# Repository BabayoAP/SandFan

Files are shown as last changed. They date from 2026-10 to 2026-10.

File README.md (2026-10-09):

# SandFan

My project for Half-Life by Hack Club!

Meant for climbers, a two-in-one portable device:
 - Variable speed enclosed fan for drying out wet hands on one side.
 - Variable speed skin-sander for grinding down overgrown calluses.

## How it works
A Seeed XIAO RP2040 is the controller. It sits on a 1S LiPo battery through a slide switch.

- **Power:** The battery feeds the motors directly (about 3.0 to 4.2 V). An AP2112K low-dropout regulator makes 3.3 V for the logic. The XIAO's own USB-C port charges the battery through an MCP73831 charger (about 200 mA), so there is no second USB connector. The battery can be charged while the switch is off.
- **Motor drive:** Each motor has its own AO3400A logic-level N-MOSFET on the low side, driven by a 20 kHz PWM pin from the RP2040. A 100 ohm gate resistor and a 100k pulldown keep the motors off while the MCU boots. An SS14 flyback diode and a 100 nF cap sit across each motor.
- **Stall protection:** The sander's MOSFET source goes to ground through a 0.1 ohm shunt. The voltage across it is filtered (1k and 100 nF) and read by an ADC pin. If the current stays above the limit for 150 ms, the firmware stops the sander and holds it off for 2 s, blinking its LED.
- **Buttons:** Five tactile buttons: fan up, fan down, sander up, sander down, and stop (everything off). Speed has 5 steps per motor. Three LEDs show fan, sander and charge state.
- **Low battery:** A 1:2 divider lets the MCU read the battery voltage. Motors are cut off below 3.3 V.

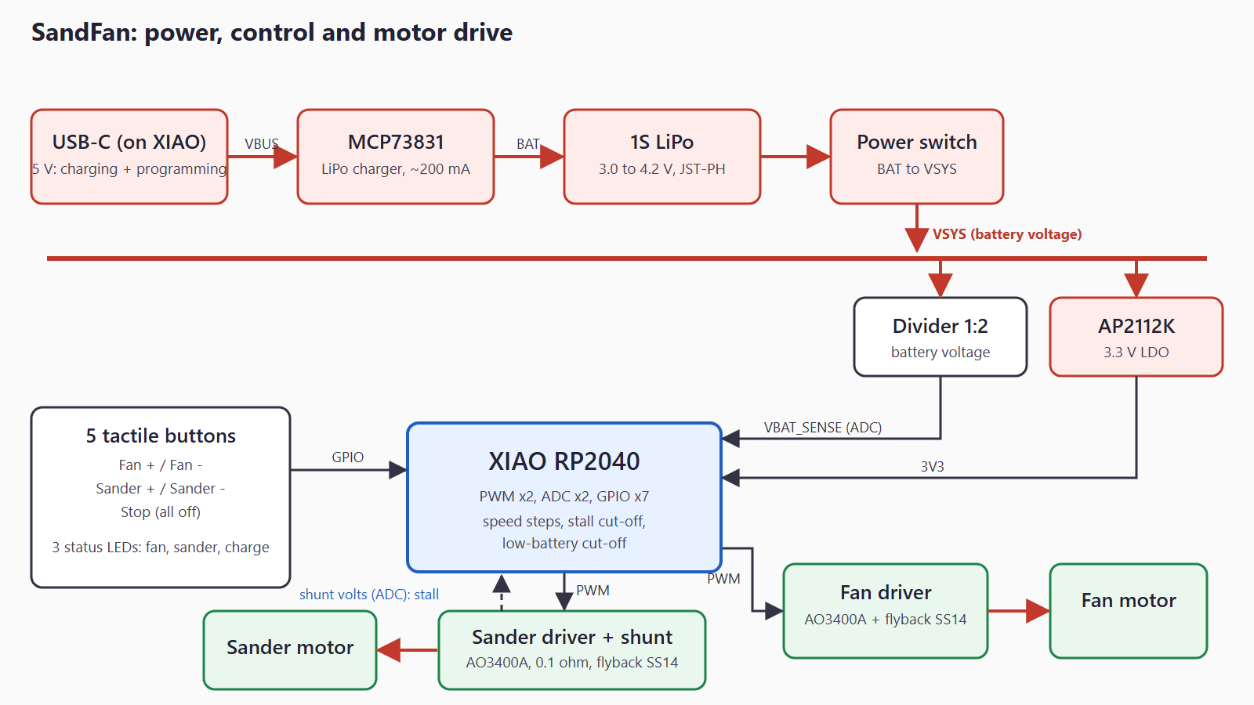
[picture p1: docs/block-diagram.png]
Block diagram


## Schematic and board
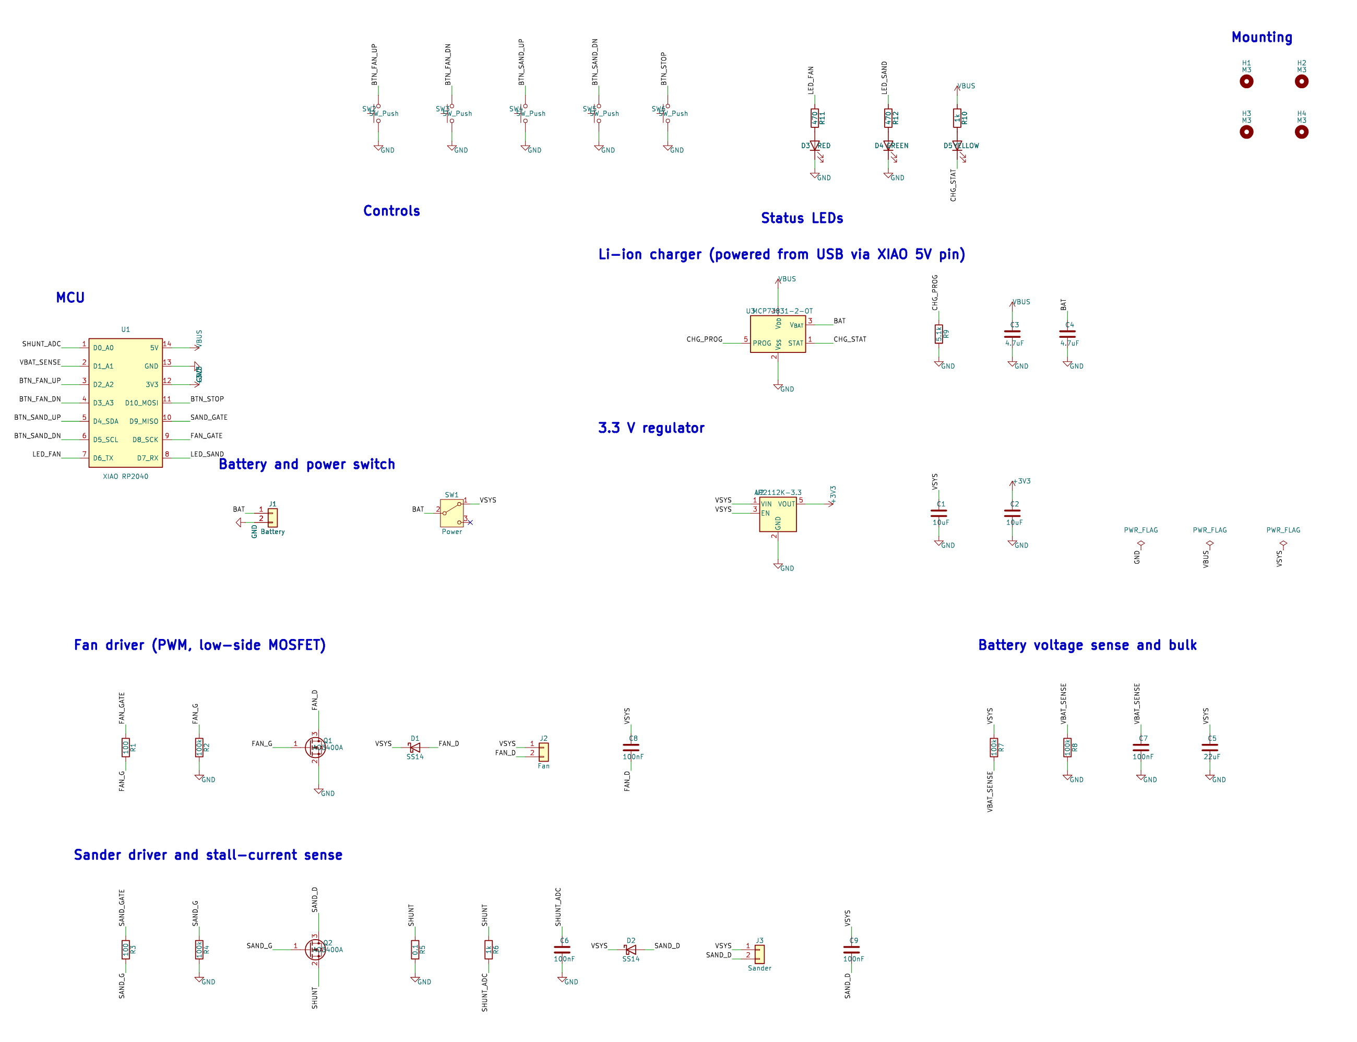
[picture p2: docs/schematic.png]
Schematic

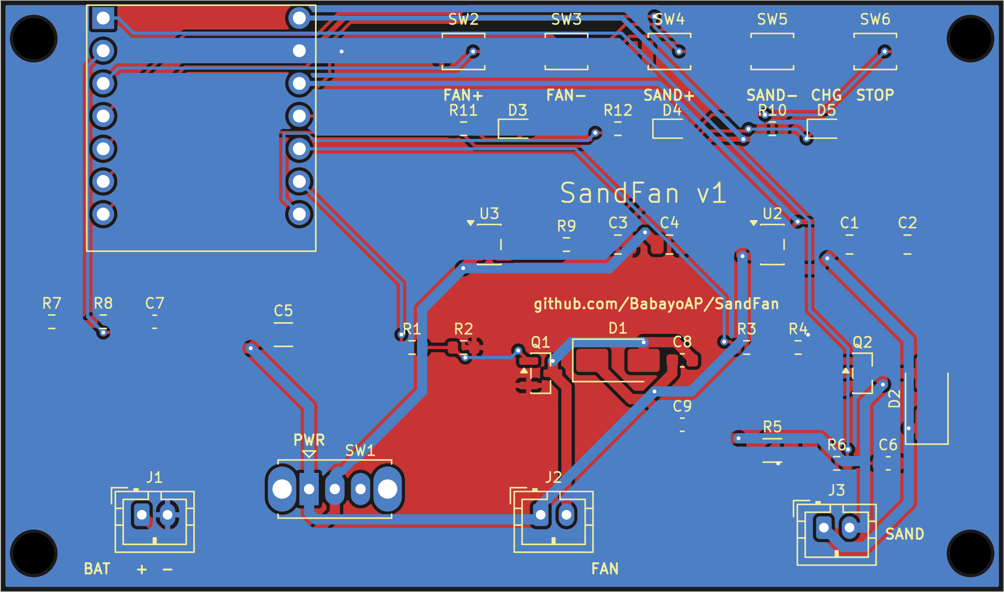
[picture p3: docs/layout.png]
Board layout

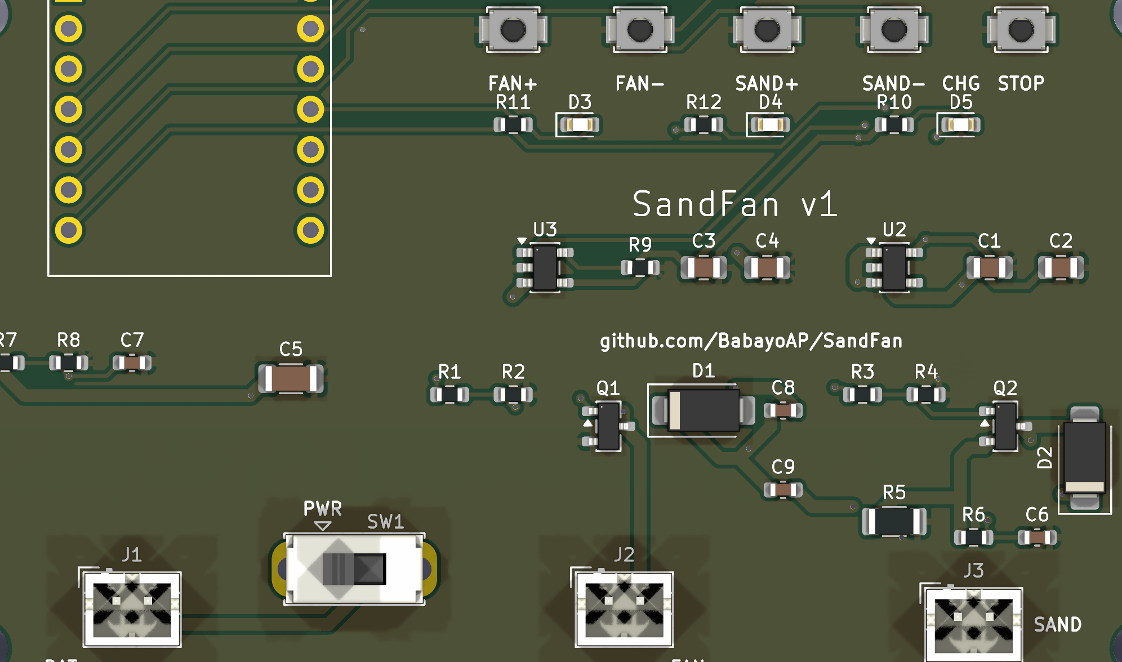
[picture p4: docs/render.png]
3D render


The board is 78 x 46 mm, two layers, with a ground pour on both sides. The XIAO's USB-C port sits at the board edge. ERC and DRC both pass with 0 violations in KiCad 10.

## Wiring
Everything on the board is soldered. The only hand-wired parts are the three things that plug in with JST-PH 2-pin connectors:

| Connector | Pin 1 | Pin 2 |
|---|---|---|
| J1 Battery | + | - |
| J2 Fan motor | VSYS (battery +) | motor return (switched by MOSFET) |
| J3 Sander motor | VSYS (battery +) | motor return (switched by MOSFET) |

LiPo packs are not standardized. Check your pack's polarity before plugging it in. Use a protected cell. Motor polarity only sets the spin direction.

## Bill of materials
| Part | Qty | Price | Link |
|---|-----|---|---|
| Seeed XIAO RP2040 (plus 2x 1x7 2.54 mm headers) | 1 | TBD | TBD |
| MCP73831T-2ACI/OT charger | 1 | TBD | TBD |
| AP2112K-3.3 regulator | 1 | TBD | TBD |
| AO3400A N-MOSFET | 2 | TBD | TBD |
| SS14 Schottky diode (SMA) | 2 | TBD | TBD |
| 0.1 ohm 1% 0.5 W resistor (1206) | 1 | TBD | TBD |
| B3U-1000P tactile switch | 5 | TBD | TBD |
| OS102011MS2QN1 slide switch | 1 | TBD | TBD |
| JST-PH B2B-PH-K-S connector | 3 | TBD | TBD |
| LEDs 0603 (red, green, yellow) | 3 | TBD | TBD |
| Resistors 0603 (100, 470, 1k, 5.1k, 100k) | 12 | TBD | TBD |
| Capacitors (100 nF, 4.7 uF, 10 uF, 22 uF) | 9 | TBD | TBD |
| 1S LiPo battery, protected | 1 | TBD | TBD |
| Fan motor and sander motor | 2 | TBD | TBD |

Prices and links get filled in when parts are ordered. The full line-by-line list with designators is in [bom.csv](bom.csv).

## Repo layout
- hardware/ : KiCad files, Gerbers zip
- firmware/ : source code
- docs/ : images
- bom.csv

## Status and next steps
**Done:** schematic, PCB (fully routed), Gerbers and drill files (`hardware/sandfan_gerbers.zip`), BOM, firmware first draft.

**Checked:** ERC and DRC pass in KiCad 10.0.6. The schematic netlist was cross-checked against the intended connections, and the board has 0 unconnected items.

**Not yet tested:**
- The firmware has not been compiled or run. It targets the arduino-pico core on a XIAO RP2040 and its pin map matches the schematic.
- No board has been built. The XIAO footprint (2x7, 2.54 mm pitch, 15.24 mm between rows) is from memory of the module, so measure the real module against it before ordering.
- The motors are not chosen yet. The stall current limit (1.5 A) and the 0.1 ohm shunt need to be sized to the real sander motor, and the shunt should be rated for the stall current.
- When USB is plugged in, the XIAO's own 3.3 V regulator and the AP2112K both drive the 3V3 rail. This is expected to be fine, but it is not verified on hardware.

**Build week:** order the board and parts, build it, compile and flash the firmware, tune the stall threshold with the real motor, then pick an enclosure and fit the fan and sander.

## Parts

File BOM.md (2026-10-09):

# SandFan – bill of materials

<!-- Generated by Half Life from project cmuuucq2k0am301smbv5bwrh2. Edits here are overwritten on the next sync. -->
<!-- Generated: 2026-10-09T06:47:38.833Z -->

> [!NOTE]
> This parts list is mirrored from [Half Life](https://halflife.hackclub.com). Editing it here will not change the platform's copy, and the next sync overwrites this file.

| Week | Tier | Parts funding |
| --- | --- | --- |
| Week 1 | Tier 3 | $100.00 |

| Part | What it's for | Qty | Unit | Total | Vendor |
| --- | --- | --- | --- | --- | --- |
| [WINSINN 50mm 5015 Blower Fan 5V, 4-pack](https://www.amazon.com/WINSINN-6000PRM-Hydraulic-50mmx15mm-Brushless/dp/B0DJQTXQ6D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) | Key c6000PRM, 3D Printer 5 Volt Fans Blower Turbine Turbo Homponent: move air over climber's hand to dry and remove sweat | 1 | $10.99 | $10.99 | [Amazon](https://www.amazon.com/WINSINN-6000PRM-Hydraulic-50mmx15mm-Brushless/dp/B0DJQTXQ6D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) |
| [2Pcs DC 6V 1000RPM Gear Motor](https://www.amazon.com/1000RPM-Geared-Gearwheel-Reduction-Robort/dp/B0DK77J793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) | Drives the callus sanding drum | 1 | $8.99 | $8.99 | [Amazon](https://www.amazon.com/1000RPM-Geared-Gearwheel-Reduction-Robort/dp/B0DK77J793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) |
| [Gebildet 2pcs PWM Low Voltage Motor Speed Controller DC](https://www.amazon.com/Gebildet-Adjustable-Driver-Controller-Voltage/dp/B08JPS6DDP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) | Dynamically controls the speed of the blower fan and the sander motor independently. | 1 | $5.69 | $5.69 | [Amazon](https://www.amazon.com/Gebildet-Adjustable-Driver-Controller-Voltage/dp/B08JPS6DDP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) |
| [Samsung 30Q 18650 3000mAh 15A Battery](https://www.18650batterystore.com/products/samsung-30q?_pos=1&_sid=ea73f6b51&_ss=r) | Energy Storage | 1 | $6.99 | $6.99 | [18650batterystore](https://www.18650batterystore.com/products/samsung-30q?_pos=1&_sid=ea73f6b51&_ss=r) |
| [Aokin 4pcs 18650 Battery Holder Bundle with Wire](https://www.amazon.com/Aokin-Battery-Storage-Parallel-Batteries/dp/B07Q13T3RH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) | Holding batteries, and providing contacts/leads | 1 | $4.99 | $4.99 | [Amazon](https://www.amazon.com/Aokin-Battery-Storage-Parallel-Batteries/dp/B07Q13T3RH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) |
| [ISDVBUY Mini Rocker Switch, 5-pack](https://www.amazon.com/ISDVBUY-Rocker-Electrical-Projects-Electricians/dp/B0DX6F2N4V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) | On/off switch | 1 | $3.99 | $3.99 | [Amazon](https://www.amazon.com/ISDVBUY-Rocker-Electrical-Projects-Electricians/dp/B0DX6F2N4V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) |
| [AOICRIE 6pcs Type-C USB 5V 2A Boost Converter](https://www.amazon.com/AOICRIE-Converter-Discharge-Integrated-Protection/dp/B0DLGTM47G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) | Charges battery via USB-C and protects it, boosts 3.7V to 5V for motors | 1 | $8.99 | $8.99 | [Amazon](https://www.amazon.com/AOICRIE-Converter-Discharge-Integrated-Protection/dp/B0DLGTM47G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) |
| [22awg Silicone Electrical Wire Cable 2 Colors](https://www.amazon.com/Electrical-Gauge-Silicone-Cable-Black/dp/B0746HG158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) | Connects battery, switch, controllers, and motors | 1 | $5.18 | $5.18 | [Amazon](https://www.amazon.com/Electrical-Gauge-Silicone-Cable-Black/dp/B0746HG158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) |
| [M2 M3 M4 Self Tapping Screws for Plastic, Carbon Steel](https://www.amazon.com/Tapping-Screws-Plastic-Carbon-Steel/dp/B0H8CD8MYV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) | Fasten the components and enclosure together | 1 | $8.99 | $8.99 | [Amazon](https://www.amazon.com/Tapping-Screws-Plastic-Carbon-Steel/dp/B0H8CD8MYV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) |
| [210 Pcs Heat Shrink Tubing Kit](https://www.amazon.com/Eugiichr-210PCS-Heat-Shrink-Tubing/dp/B0GGGY2HFJ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) | Wiring insulation | 1 | $6.19 | $6.19 | [Amazon](https://www.amazon.com/Eugiichr-210PCS-Heat-Shrink-Tubing/dp/B0GGGY2HFJ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) |
| [Gebildet 3V-6V-12V-24V-230V/1A 10pcs](https://www.amazon.com/Gebildet-3V-6V-12V-24V-230V-Prewired-Momentary-Railway/dp/B0CJHXJWN3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) | Primary switch for power, backup for rocker switch | 1 | $5.99 | $5.99 | [Amazon](https://www.amazon.com/Gebildet-3V-6V-12V-24V-230V-Prewired-Momentary-Railway/dp/B0CJHXJWN3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) |
| **Parts subtotal** | — | — | — | **$76.98** | — |
| **Tax & shipping** | — | — | — | **$14.43** | — |
| **Total** | — | — | — | **$91.41** | — |

$8.59 left of the tier's funding.

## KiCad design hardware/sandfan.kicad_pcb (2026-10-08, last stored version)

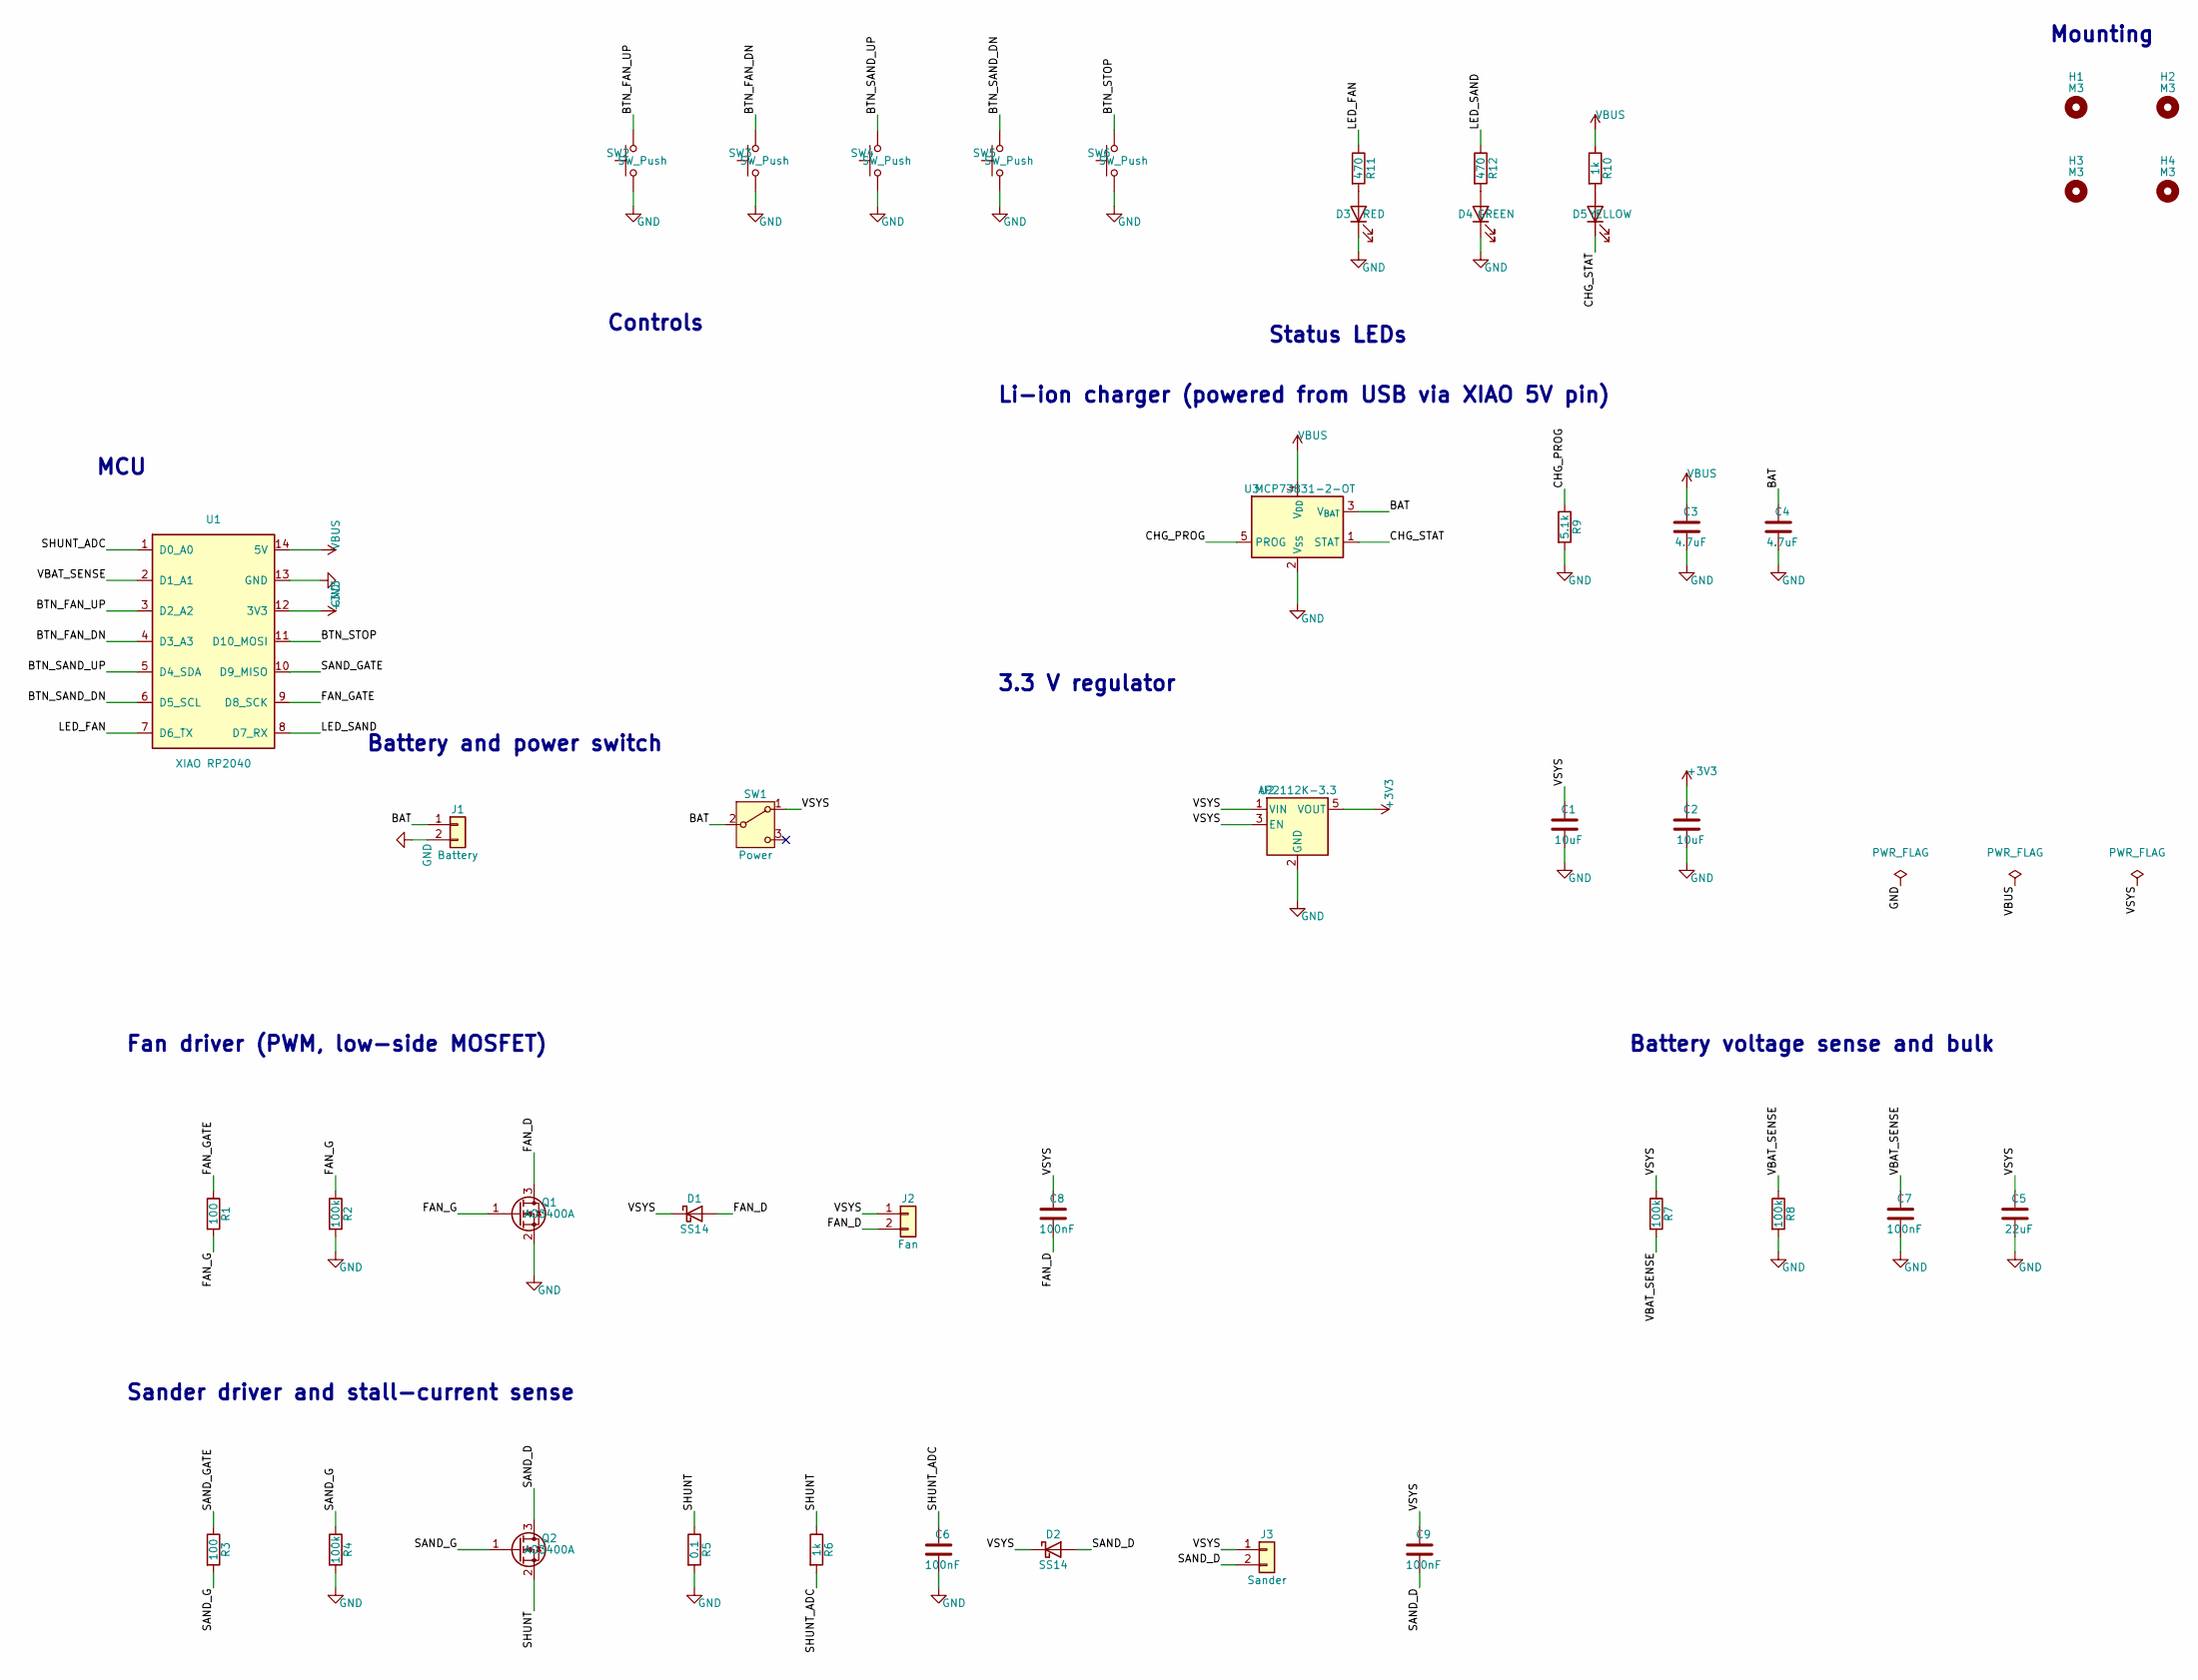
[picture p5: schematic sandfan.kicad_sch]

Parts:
C1, C2: 10uF; C_0805_2012Metric
C3, C4: 4.7uF; C_0805_2012Metric
C5: 22uF; C_1206_3216Metric
C6, C7, C8, C9: 100nF; C_0603_1608Metric
D1, D2: SS14; D_SMA; MPN SS14
D3: RED; LED_0603_1608Metric
D4: GREEN; LED_0603_1608Metric
D5: YELLOW; LED_0603_1608Metric
H1, H2, H3, H4: M3; MountingHole_3.2mm_M3
J1: Battery; JST_PH_B2B-PH-K_1x02_P2.00mm_Vertical; MPN B2B-PH-K-S
J2: Fan; JST_PH_B2B-PH-K_1x02_P2.00mm_Vertical; MPN B2B-PH-K-S
J3: Sander; JST_PH_B2B-PH-K_1x02_P2.00mm_Vertical; MPN B2B-PH-K-S
Q1, Q2: AO3400A; SOT-23; MPN AO3400A
R1, R3: 100; R_0603_1608Metric
R2, R4, R7, R8: 100k; R_0603_1608Metric
R5: 0.1; R_1206_3216Metric
R6, R10: 1k; R_0603_1608Metric
R9: 5.1k; R_0603_1608Metric
R11, R12: 470; R_0603_1608Metric
SW1: Power; SW_Slide_SPDT_Straight_CK_OS102011MS2Q; MPN OS102011MS2QN1
SW2, SW3, SW4, SW5, SW6: SW_Push; SW_SPST_B3U-1000P; MPN B3U-1000P
U1: XIAO RP2040; XIAO_RP2040_Socket; MPN Seeed Studio XIAO RP2040
U2: AP2112K-3.3; SOT-23-5; MPN AP2112K-3.3TRG1
U3: MCP73831-2-OT; SOT-23-5; MPN MCP73831T-2ACI/OT

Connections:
+3V3: C2.1, U1.12 (3V3), U2.5 (VOUT)
/BAT: C4.1, J1.1, SW1.2 (B), U3.3 (V_{BAT})
/BTN_FAN_DN: SW3.2, U1.4 (D3_A3)
/BTN_FAN_UP: SW2.2, U1.3 (D2_A2)
/BTN_SAND_DN: SW5.2, U1.6 (D5_SCL)
/BTN_SAND_UP: SW4.2, U1.5 (D4_SDA)
/BTN_STOP: SW6.2, U1.11 (D10_MOSI)
/CHG_PROG: R9.1, U3.5 (PROG)
/CHG_STAT: D5.1 (K), U3.1 (STAT)
/FAN_D: C8.2, D1.2 (A), J2.2, Q1.3 (D)
/FAN_G: Q1.1 (G), R1.2, R2.1
/FAN_GATE: R1.1, U1.9 (D8_SCK)
/LED_FAN: R11.1, U1.7 (D6_TX)
/LED_SAND: R12.1, U1.8 (D7_RX)
/SAND_D: C9.2, D2.2 (A), J3.2, Q2.3 (D)
/SAND_G: Q2.1 (G), R3.2, R4.1
/SAND_GATE: R3.1, U1.10 (D9_MISO)
/SHUNT: Q2.2 (S), R5.1, R6.1
/SHUNT_ADC: C6.1, R6.2, U1.1 (D0_A0)
/VBAT_SENSE: C7.1, R7.2, R8.1, U1.2 (D1_A1)
/VSYS: C1.1, C5.1, C8.1, C9.1, D1.1 (K), D2.1 (K), J2.1, J3.1, R7.1, SW1.1 (A), U2.1 (VIN), U2.3 (EN)
GND: C1.2, C2.2, C3.2, C4.2, C5.2, C6.2, C7.2, D3.1 (K), D4.1 (K), J1.2, Q1.2 (S), R2.2, R4.2, R5.2, R8.2, R9.2, SW2.1, SW3.1, SW4.1, SW5.1, SW6.1, U1.13 (GND), U2.2 (GND), U3.2 (V_{SS})
unnamed: D3.2 (A), R11.2
unnamed: D4.2 (A), R12.2
unnamed: D5.2 (A), R10.2
VBUS: C3.1, R10.1, U1.14 (5V), U3.4 (V_{DD})

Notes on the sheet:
MCU
Controls
Status LEDs
Li-ion charger (powered from USB via XIAO 5V pin)
3.3 V regulator
Battery and power switch
Fan driver (PWM, low-side MOSFET)
Sander driver and stall-current sense
Battery voltage sense and bulk
Mounting

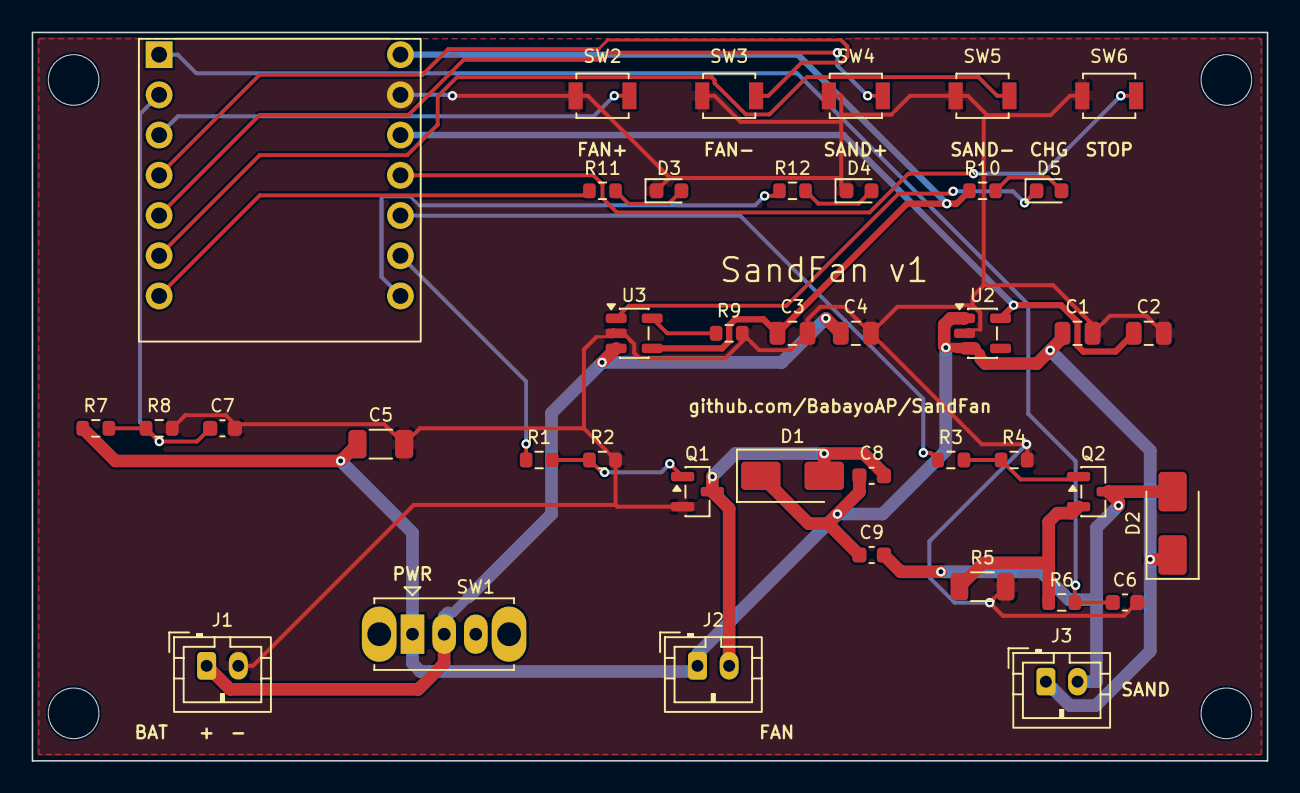
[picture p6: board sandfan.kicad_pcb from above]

Board: 2 copper layers, 78.0 x 46.0 mm, 44 parts (0 on the bottom side), 26 nets.

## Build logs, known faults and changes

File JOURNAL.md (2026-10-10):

# SandFan – devlog

<!-- Generated by Half Life from project cmuuucq2k0am301smbv5bwrh2. Edits here are overwritten on the next sync. -->
<!-- Generated: 2026-10-10T07:24:10.676Z -->

> [!NOTE]
> This devlog is mirrored from [Half Life](https://halflife.hackclub.com). Editing it here will not change the platform's copy, and the next sync overwrites this file.

> Meant for climbers, a two-in-one portable device:  - Variable speed enclosed fan for drying out wet hands on one side.  - Variable speed skin-sander for grinding down overgrown calluses.

| Week | Tier | Hours logged | Entries |
| --- | --- | --- | --- |
| Week 1 | Tier 3 | 7.38h | 4 |

## Contents

1. [2026-10-06 – October 6:](#2026-10-06-october-6)
2. [2026-10-08 – October 8:](#2026-10-08-october-8)
3. [2026-10-09 – Work session](#2026-10-09-work-session)
4. [2026-10-10 – Work session](#2026-10-10-work-session)

## Design

### 2026-10-06 – October 6:

**2.5h**

October 6:
I originally set out to just start the project for today, but I had a few goals in mind after wrapping my head around what I really needed to do.

 - figure out what I wanted to build and post a video on it: originally, I tried to use TinkerCad, but that proved a little too time-consuming, so I built a 2d version in Miro instead.

2D Miro video

scrapped 3d model

 - get my repo check done, I used claude code for the majority of this (more on this later!), specifically the PCD on KiCad and the firmware. But after revising the docs, I realized that it wasn't faithful to the terms and values of half-life. And next session, I'll go back, delete everything, and only use the previously generated work as a guide while doing it ALL MYSELF!

 - Things for set up I did do, setting up hackatime was challenging for me, for some reason, I was only seeing other... on the list dropdown, but after using Claude PROPERLY, finagling with GitHub repos and local repos, it all worked out and I could finally track my code hours

I couldn't see anything past the pesky other..., but now maybe I see too much?

 -  next session, I'll redo everything with proper guidance and work, and I'll finish the goals I originally set out to do ( finishing the GitHub checklist)

tldr: Learned all about the half-life process and how the program works. Learned the hard way to always check doc rules appropriately and use Claude Code appropriately, as a tool. Learned to work efficiently and focus on one task at a time.

### 2026-10-08 – October 8:

**3h**

October 8:
In the previous session, I wanted to start on the things that Claude Code had done for me before, but it became immediately clear that I had to finish the component list first. So, today I planned to finish the BOM file, getting all my components and parts down for my device. I didn't realize it would be so hard, though. I truly thought it would be a 1-hour task max.

1. I had a first iteration of the parts list. I thought it would be the last one, so I didn't take a screenshot. It was mostly full of negative things, but it was a great learning experience:
 - I didn't realize how interconnected devices were; it didn't have wiring, insulation, and the battery pack was quite simplistic
 - It really didn't follow my original plan. I had an external battery, an overkill motor, and components of wildly different sizes.
 - At this point, my budget was looking great, sitting at ~$40.

1st+2nd list iteration

2. My next iteration was extremely different. I realized how many issues my original list/plan had, and I had to change many components entirely. During the process, I also learned more about how my device would work, and it changed my original design and view of what it should look like. Of course, I still ran into many issues.
 - My budget was growing higher and higher, and I thought that instead of compromising quality, I would just move my project to funding tier 3.
2nd list iteration
 - It really opened up my eyes to the process of creating a new product; everything was relatively expensive, but the shipping was the real killer. I had to rely on Amazon HEAVILY in order to get past shipping costs.
 - After finagling with different products and shipping settings, I managed to maximize my quality vs budget ratio, and finally arrived at a list that I was happy with. I ran it through Claude, and it said that my list was good.
Final part list

Hopefully, I can have my next session tomorrow. I'd like to start on the PCB and design.

tldr: Finding components is hard, and it takes a lot longer than I thought. I'm impressed by how cheap some factories can make items. I understand electronics pricing now. Starting over isn't a bad thing, and don't compromise on quality. Tomorrow is the start of design.

### 2026-10-09 – Work session

**0.73h**

[Timelapse](https://lookout.hackclub.com/api/media/8a261ef4-3633-4f73-bb10-0c387b341d15/video.mp4)

### 2026-10-10 – Work session

**1.15h**

[Timelapse](https://lookout.hackclub.com/api/media/1cc06fdf-eecc-4f12-9b0b-f18cb2ff5a96/video.mp4)

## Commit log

2026-10-08 Add SandFan hardware, firmware, BOM, and docs
    KiCad schematic and PCB, gerbers, XIAO RP2040 firmware, bill of materials, and README images.
    [bom.csv, sandfan.kicad_pcb, sandfan.kicad_sch]
2026-10-09 Remove Claude-generated files to restart from scratch
    [bom.csv, sandfan.kicad_pcb, sandfan.kicad_sch]
2026-10-12 Add routed PCB, Gerbers, BOM and board/schematic images
2026-10-12 Update README with analog design details
    Added information about the device's analog design.
